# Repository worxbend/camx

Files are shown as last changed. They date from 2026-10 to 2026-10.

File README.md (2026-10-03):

<div align="center">

# 📷 CAMX

### Your webcam just unlocked movement. ✨

**ESP32 brains. Two tiny servos. One printable pan & tilt rig.**







[**🎛️ Try the control desk**](https://worxbend.github.io/camx/control/?demo=1) · [**🌀 Open the 3D studio**](https://worxbend.github.io/camx/) · [**📦 Get the downloads**](https://github.com/worxbend/camx/releases/latest) · [**🛠️ Build guide**](docs/assembly.md)

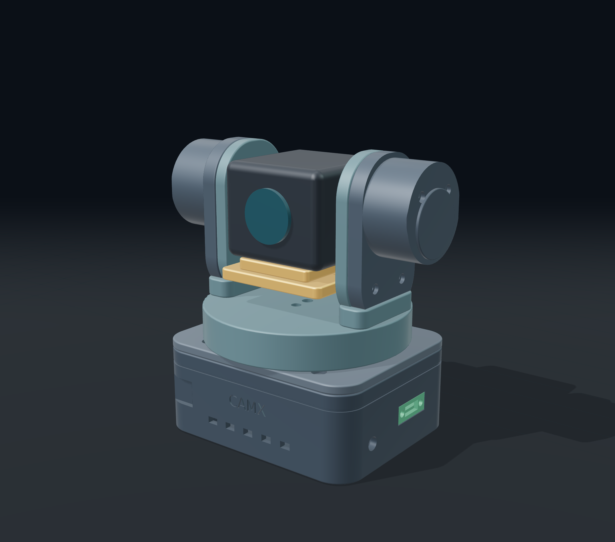
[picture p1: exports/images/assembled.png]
CAMX — actual CAD geometry rendered in the 3D studio


</div>

---

## ✨ The vision

Take an Anker PowerConf webcam. Give it a smooth pan axis, a balanced tilt cradle, and a rounded enclosure that actually looks like a device you'd keep on your desk.

The compact version uses a **100 × 82 × 38 mm base**, a **Ø92 mm pan platform** and shallow lower side shells. The complete neutral assembly is **126.6 × 91.5 × 127 mm**, including the two pivot housings. Camera fit targets the owner-stated **50 mm-wide camera**, represented by a **50 × 51 × 41 mm envelope**; verify your exact PowerConf model and folded clip.

CAMX follows the owner's hand-drawn concept: **a curved camera cradle and an ESP32 beside the pan servo in the base**, rebuilt to match your revised sketch with **matching rounded arm housings, mirrored pivot caps, a circular pan platform and a U-shaped support**. The passive housing has the same outer shape as the servo side, with bearing hardware inside. Integral standoffs let both outer covers attach with short M2 × 8 mm screws. The camera bolts on through its existing **1/4″-20 tripod thread**. The tilt-servo lead has a rear shell exit, arm tie eyes, a pan-platform notch and a separate rear base entry. An orange neutral-pose guide shows its route in the viewer; leave an external service loop for pan. The USB-C panel board and **1000 µF capacitor** get dedicated space inside. The visible USB-C metal flange fits a recessed pocket in the right wall, 0.2 mm below its outer surface, with reinforced backing and internal nuts.

> 🧪 **Prototype, with receipts.** The firmware compiles and **615 CAD/mesh/clearance checks pass**. Hardware dimensions are still provisional; physical fit and load testing are the next step. Print the fit coupon first.

**Readiness:** ready for controlled prototype commissioning after fit/power checks. Physical validation remains pending, and the Python CAD/image toolchain has an unresolved Pillow dependency constraint and 13 security alerts. Firmware/browser production audits have no known findings. [Final audit and limitations →](docs/design/remote-qa.md)

## 🌀 Spin it before you print it

[**Launch the live viewer →**](https://worxbend.github.io/camx/)

Drag to orbit. Scroll to zoom. Preview **±60° pan** and **±25° tilt**, pull the assembly apart with the explode slider, toggle hardware or wireframe, and hide individual parts. It works on desktop and phone.

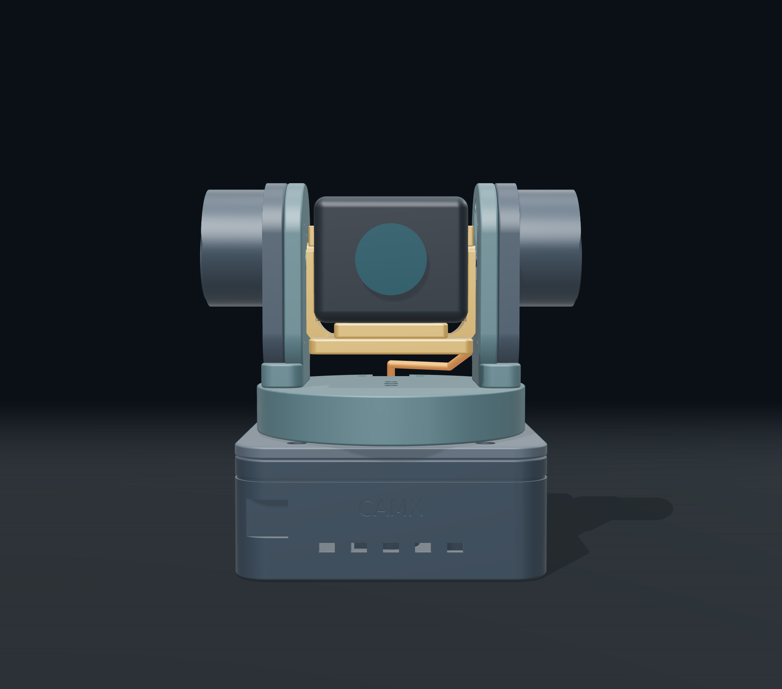
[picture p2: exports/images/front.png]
Symmetrical U-yoke — actual CAD front view


The viewer loads the **actual CAD GLB**. The webcam, PCB, servos and capacitor are simplified hardware envelopes. This site previews the design; it does not send commands to your motors.

## 📦 Pick your download

| You want… | Grab this |
| --- | --- |
| The whole project, source included | [`camx-project.zip`](https://github.com/worxbend/camx/releases/latest/download/camx-project.zip) |
| Straight to the slicer | [`camx-print-parts.zip`](https://github.com/worxbend/camx/releases/latest/download/camx-print-parts.zip) |
| ESP32 source + binaries + LittleFS client | [`camx-firmware.zip`](https://github.com/worxbend/camx/releases/latest/download/camx-firmware.zip) |
| A website you can host yourself | [`camx-viewer.zip`](https://github.com/worxbend/camx/releases/latest/download/camx-viewer.zip) |
| SolidJS control app + local bridge | [`camx-control.zip`](https://github.com/worxbend/camx/releases/latest/download/camx-control.zip) |
| File integrity checks | [`checksums.sha256`](https://github.com/worxbend/camx/releases/latest/download/checksums.sha256) |

Tagged releases publish these files automatically. Between releases, download the **camx-release-files** artifact from a successful [Build & release run](https://github.com/worxbend/camx/actions/workflows/release.yml). Artifacts are retained for 30 days; releases are the durable download location. The committed [full project bundle](exports/camx-files.zip) is also available.

**Formats on deck:** STL · 3MF · STEP · BREP · OBJ · PLY · OFF · GLB · glTF · SVG · DXF · PNG · JPEG · WebP · TIFF.

## 🧩 What's inside

| Part of the project | What it does |
| --- | --- |
| [🎛️ Firmware](firmware/) | 50 Hz servo PWM, synchronized jerk-limited S-curves, Wi-Fi controls, serial commands, saved calibration and latched STOP |
| [📐 Parametric CAD](cad/) | Thirteen printable parts, stock servo horn interfaces, adjustable component dimensions |
| [🌀 3D studio](viewer/) | Orbit, pan/tilt previews, explode, wireframe, part visibility and downloads |
| [🛠️ Assembly guide](docs/assembly.md) | Wiring, fasteners, print orientation, balance and first startup |
| [✅ Validation](exports/validation.json) | CAD solids, watertight STL/3MF meshes and sampled clearance checks |
| [🎛️ Control client](client/) | SolidJS 2 hold-to-move remote, presets, calibration, guides and local bridge |
| [🚀 GitHub Actions](.github/workflows/) | Firmware/CAD rebuilds, viewer tests, release downloads and Pages deployment |

### 🖨️ Thirteen printed pieces. Zero printed spline teeth.

`drive_arm` · `base` · `lid` · `pan_arm` · `camera_cradle` · `tilt_cover` · `bearing_retainer` · `spindle_keeper` · `tripod_nut_retainer` · `idler_cover` · `fit_coupon` · `idler_arm` · `idler_bearing_retainer`

Use your servos' original horns and center screws. A **6805 bearing (25 × 37 × 7 mm)** supports the pan platform. Steel hardware provides the camera screw and captive tripod nut.

## 🔌 The hardware lineup

- 📷 Anker PowerConf webcam — confirm the exact model, dimensions, mass and thread depth.
- 🎛️ ESP32-WROOM-32 DevKit — the photographed board has a USB-C programming port.
- ⚙️ **2 × positional SG90-type micro servos** — continuous-rotation models won't follow angles.
- 🔋 Regulated **5 V / 3 A PSU** and **1000 µF electrolytic**, rated at least 10 V.
- 🔗 Your panel USB-C module — verify its pinout, CC resistors and current rating.
- 🛞 One 6805 pan bearing and one 625 tilt bearing, fasteners, zip ties and a 1/4″-20 camera screw/nut.

**GPIO18 → pan · GPIO19 → tilt · GPIO33 → optional STOP button.** Common ground for everything. Camera USB stays connected directly to the PC. Servo power comes from the PSU, not the ESP32's 3V3 rail.

[**Read the wiring and source-isolation notes before powering up →**](docs/assembly.md#wiring)

## ⚡ First boot

1. Measure your components and update [`cad/parameters.json`](cad/parameters.json).
2. Print the **fit coupon**, then dry-fit the empty mechanism.
3. Keep servos disconnected during flashing. Follow the guide when using USB and external power.
4. Copy [`credentials.example.h`](firmware/include/credentials.example.h) to `firmware/include/credentials.h` (gitignored), set your Wi-Fi credentials and API token, rebuild and flash. Open the IP printed by the serial monitor after connection.
5. Center the servos with their horns removed, assemble, balance the camera, and expand travel carefully.

**PWM starts disabled.** STOP holds the current commanded position; DISARM releases torque. Support the camera before disabling PWM. Servo angles are commanded estimates, not encoder measurements. Automatic face tracking would require a separate host application; it is not included in this firmware.

## 🎮 A real remote. In your browser.

The **SolidJS 2** client gives CAMX a real operator interface: a sculpted press-and-hold directional pad, diagonal multi-touch, optional held keyboard arrows, three speed levels, editable presets, JSON backups, live status and a bounded activity log. A dedicated calibration workspace includes pulse settings, inversion, speed, measured travel limits, and a four-step walkthrough. Wiring, assembly and Wi-Fi guides are built in.

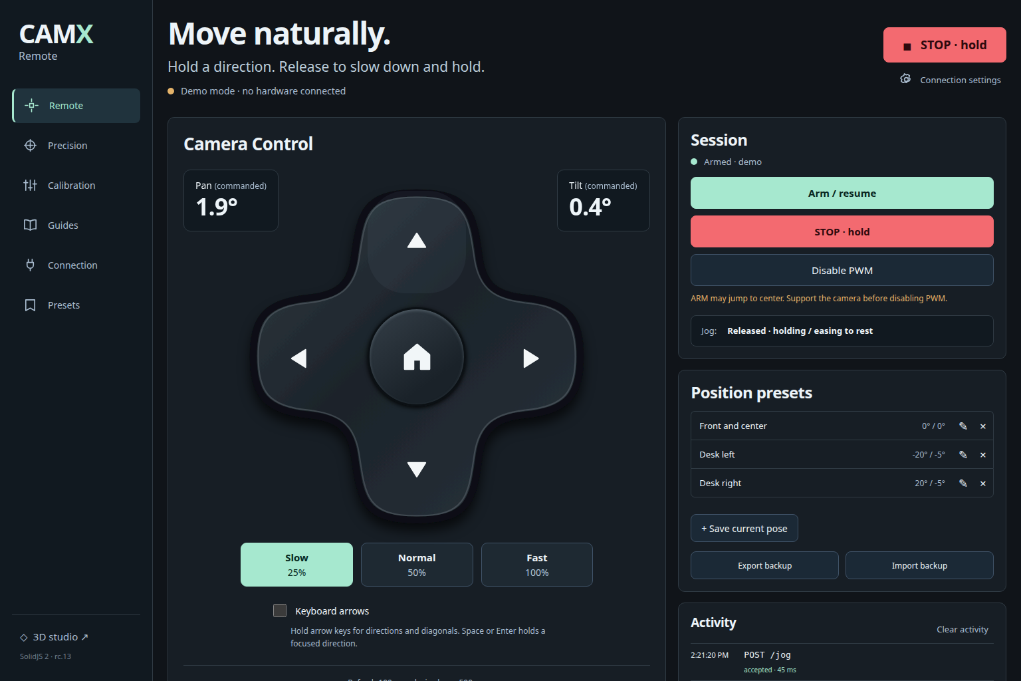
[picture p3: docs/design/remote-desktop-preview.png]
CAMX remote — actual browser interface in demo mode


**Hold to move. Release to brake smoothly.** A normalized velocity pair is refreshed every 100 ms. Firmware stops and latches if the jog lease is not renewed within 500 ms. Pointer cancellation, hidden tabs and connection loss clear held inputs; returning never resumes them. The Precision tab retains combined angle targets, sliders and fine nudges. [Why this protocol? →](docs/jog-design.md)

**STOP stays visible.** Connecting never arms the servos. Calibration saves only with PWM disabled. The optional control lease starts off; losing the connection cancels queued motion and reconnection requires deliberate ARM. Tokens remain in memory and stay out of backups and browser storage.

[**Explore the safe demo →**](https://worxbend.github.io/camx/control/?demo=1) · [**Install on your ESP32 →**](docs/control-client.md) · [**Download the client →**](https://github.com/worxbend/camx/releases/latest/download/camx-control.zip)

The Pages version is a simulation. For real control, serve the client directly from the ESP32's **LittleFS** partition at `http://DEVICE_IP/control/`, or run the included **localhost LAN bridge**. No cloud account or Internet connection is needed after installation. Webcam video and face tracking are separate host-side concerns.

SolidJS 2 is pinned to **2.0.0-rc.13**, with matching web runtime/compiler packages. It is a release candidate; dependencies and the lockfile are committed. Node 24 is recommended. [Official Solid releases](https://github.com/solidjs/solid/releases).

```sh
npm --prefix client ci
npm --prefix client run build
npm --prefix client run stage:firmware
.venv/bin/pio run -d firmware -t buildfs
# Upload configured firmware + filesystem after reviewing wiring/power isolation.
.venv/bin/pio run -d firmware -t upload
.venv/bin/pio run -d firmware -t uploadfs
```

For a desktop control station:

```sh
CAMX_DEVICE_URL=http://DEVICE_IP npm --prefix client run serve
# Open http://127.0.0.1:4175/control/
```

## 🛝 Smooth moves, built into firmware

Each accepted pan/tilt target uses a synchronized **jerk-limited S-curve**: gentle start, gradual acceleration, bounded top speed, then gradual deceleration to zero velocity and acceleration. The existing calibration **Speed** is the maximum speed, not a constant-rate jump. At the default settings, a 30° pan move from rest takes about **2.4 seconds**. Short moves reach a lower peak speed automatically.

New targets preserve the current commanded position, velocity and acceleration. Repeating the same target does not restart the ramp. The complete calculated path must stay within saved limits, including braking before a reversal. **STOP, Wi-Fi loss, watchdog expiry and DISARM remain immediate**; emergency stops do not wait for easing. Normal remote release brakes smoothly; emergency STOP holds immediately. For an absolute move longer than five seconds, explicitly enable the client's Maintain control lease or send accepted heartbeat/commands.

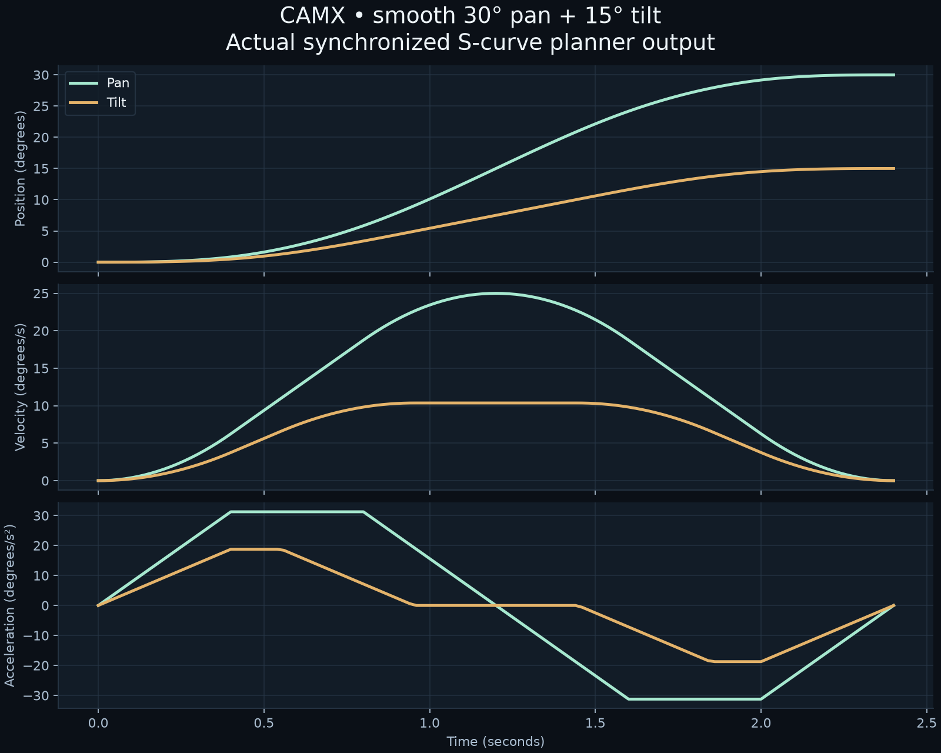
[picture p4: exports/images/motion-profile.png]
Actual firmware planner — 30° pan and 15° tilt move


The offline planner uses the vendored MIT-licensed [Ruckig 0.15.3 core](firmware/lib/ruckig/UPSTREAM.md). SG90 backlash, deadband, pulse resolution and camera balance still affect physical smoothness; there is no encoder feedback. Physical motion has not yet been verified.

## 📡 LAN control

The ESP32 joins your **2.4 GHz Wi-Fi** and serves HTTP on port 80. Send both center-relative offsets in one request; repeats do not accumulate movement. [API and hardening details →](docs/firmware-api.md)

```sh
curl -X POST http://DEVICE_IP/arm -H 'X-CAMX-Request: 1' -H "Authorization: Bearer $CAMX_TOKEN"
curl http://DEVICE_IP/move -H 'X-CAMX-Request: 1' -H "Authorization: Bearer $CAMX_TOKEN" \
  -H 'Content-Type: application/json' -d '{"pan":15,"tilt":-5}'
```

Public downloads contain **unconfigured firmware**. Build locally with your ignored `credentials.h`; configured binaries also contain secrets and must stay private.

## 🧑‍💻 Build it yourself

```sh
# Python 3.12+ and a C++ compiler
python3 -m venv .venv
.venv/bin/pip install -r requirements.txt

# Control client + matching ESP32 filesystem
npm --prefix client ci
npm --prefix client run build
npm --prefix client run stage:firmware

# Firmware + CAD + print validation
.venv/bin/pio run -d firmware
.venv/bin/pio run -d firmware -t buildfs
.venv/bin/python cad/model.py
.venv/bin/python tests/validate_cad.py
.venv/bin/python tools/test_motion.py

# Diagrams + download bundle
.venv/bin/python tools/diagrams.py
.venv/bin/python tools/package.py

# Browser studio — Node 22.12+ or a supported newer version
cd viewer
npm ci
npm run build
npm run dev
```

The CAD source uses millimetres. STL/3MF files are oriented for printing and sit at Z=0. STEP/BREP preserve assembly coordinates. GLB/glTF use metres with Y up. Vector projections are visualization references; the [dimension sheet](exports/drawings/dimensions.svg) lists defaults to verify.

For browser QA and polished stills, install Chromium with `npx playwright install chromium`, serve the built viewer, then run `node scripts/qa.mjs` and `node scripts/render-cad.mjs` from `viewer/`. Set `CAMX_QA_URL` to your preview URL. Run `.venv/bin/python tools/image_formats.py` from the root to encode captured previews. Matplotlib is the default headless preview fallback.

## 🚀 Ship it with Actions

**Every push / PR:** build the SolidJS client and LittleFS image → compile ESP32 firmware → test motion, parser and LAN bridge → regenerate and check CAD → test desktop/mobile controls and viewer → upload downloadable artifacts.

**Every `v*` tag:** run the same checks, then create a GitHub Release with all five ZIPs and SHA-256 checksums.

```sh
git tag v0.5.1
git push origin v0.5.1
```

**GitHub Pages:** the separate [Pages workflow](.github/workflows/pages.yml) builds and publishes the live studio and control demo on main/master pushes. Configure **Settings → Pages → Source → GitHub Actions**. All site assets ship locally; repository subpaths such as `/camx/` work without changing the Vite base.

<details>
<summary><strong>🧪 What was checked — and what still needs real hardware</strong></summary>

- Firmware compilation, pure C++ motion tests and HTTP/JSON parser fuzzing with sanitizers.
- Control-client unit/browser tests and three local bridge checks, including paired movement, calibration, cancellation, reconnect and token privacy.
- Thirteen valid CAD solids; watertight, oriented STL/3MF exports with matching bounds.
- Sampled pan/tilt clearance; the exact count is recorded in the validation report.
- Browser loading, pivots, explosion, visibility, wireframe, view presets, reset, downloads and guide navigation.
- Desktop **1536 × 1024** and mobile **390 × 844**, including a `/camx/` deployment path.
- Archive integrity and generated-file checksums.

Still to verify: your component measurements, printer tolerances, actual servo travel, cable slack, load balance, heat, jitter and durability. The opposite 625 bearing reduces cantilever loading. Matching 6 mm side plates, rounded foot joints and a compact base support the symmetrical assembly. The SG90 still carries part of the load; physical durability remains unverified. See the [structural review](docs/structural-review.md). Published SG90 stall torque is not a continuous load rating.

[Workflow decisions](docs/workflow.md) · [Visual concept and review](docs/design/fidelity-review.md) · [Viewer QA](docs/design/viewer-qa.json) · [Remote QA](docs/design/remote-qa.md)

</details>

---

<div align="center">

**Sketch → CAD → print → move.** 🖤

Built with **build123d · PlatformIO · SolidJS 2 · Three.js** by **worxbend**.

</div>

🔩 **Printed bearing-side joint:** print the [shoulder axle](exports/fasteners/printed_idler_shoulder_axle.stl), [matching captive nut](exports/fasteners/printed_idler_captive_nut.stl), outer washer and inner spacer from the [kit ZIP](exports/fasteners/printed-idler-kit.zip). No metal screw or nut is needed in this joint. Keep the 625 bearing. PETG/nylon and a supported fit/load trial are recommended; printed strength and durability remain unverified. The cradle remains 57.2 mm wide with a 51 mm camera opening.

📶 **Automatic recovery:** transient control-request failures no longer require manually reconnecting. The client retries status indefinitely and restores controls when the ESP32 responds, while cancelling interrupted holds and retaining explicit ARM after a device STOP.

📶 **Firmware 0.5.2 connection holds:** transport timeouts cancel motion and retain holding torque without requiring re-ARM. Reconnect, then press a direction again. Explicit STOP, physical STOP and PWM disable still require deliberate ARM. Update both firmware and the client filesystem.

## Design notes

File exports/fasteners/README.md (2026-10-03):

# Printed joint and legacy screw reference

For the requested printed assembly use printed_idler_shoulder_axle and printed_idler_captive_nut, plus the supplied washer/spacer. See PRINTED_JOINT.md. The FIT_ONLY file below is a separate legacy reference.

M5 × 12 mm under-head length; right-hand 0.8 mm pitch; 8.5 mm diameter × 3.5 mm slotted head. Simplified thread geometry, not an ISO tolerance-qualified manufacturing drawing.

**Printed model: fit checks only. Use a metal M5 axle screw and nut for the loaded camera assembly.** Do not force the printed thread into a metal nut. Print upright, head on the bed; inspect the recessed head slot in your slicer. No material or printer profile is included.

The 12 mm length matches the current assembly reference, but confirm your actual washer/bearing/spacer stack and ensure the tip and captive nut clear the camera before tightening. Use a 2.5 mm outer washer stack and a 2.7 mm M5 jam nut.

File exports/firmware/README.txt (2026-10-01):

Prefer PlatformIO upload. For classic ESP32 / 4MB only:
python -m esptool --chip esp32 --port YOUR_PORT write_flash 0x1000 bootloader.bin 0x8000 partitions.bin 0xe000 boot_app0.bin 0x10000 firmware.bin 0x290000 littlefs.bin
Filesystem address is validated in flash-layout.json for this build; do not reuse with a different partition table.
Public binaries are Wi-Fi unconfigured. Copy firmware/include/credentials.example.h to credentials.h, set your credentials and token, then build locally. Never publish configured binaries. Never flash only firmware.bin at address zero. See docs/assembly.md for wiring and first startup.

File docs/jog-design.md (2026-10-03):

# Hold-to-move remote: design and protocol

CAMX's primary remote sends direction and speed while a button is held. Release tells the firmware to brake smoothly and hold the resulting position. It does not keep adding angle offsets or queue a long series of target poses. Precise absolute angles remain available separately for measured positions and presets.

## Why a hold remote

A directional remote fits exploratory aiming: press right until the frame looks right, release, then adjust tilt. An explicit enable step and continuously renewed velocity intent are established teleoperation patterns. ROS `teleop_twist_joy` converts joystick input to scaled velocity commands and supports a required enable button; it delegates repeat behavior to its joystick source. CAMX applies the same general idea to browser buttons, without depending on ROS. [ROS teleop documentation](https://github.com/ros2/teleop_twist_joy)

A short command lease bounds how long missing input can continue movement. ROS's differential-drive controller offers stale-command stopping with a default 0.5-second timeout and velocity, acceleration, and jerk limits. Those are useful design precedents, not certification or evidence that a webcam mechanism is safe. CAMX's independent 500 ms jog watchdog is a project choice to be validated on its actual network and loaded mechanism. [ROS controller documentation](https://control.ros.org/rolling/doc/ros2_controllers/diff_drive_controller/doc/userdoc.html)

## PTZ precedents and mode choice

ONVIF's PTZ service separates absolute, relative, and continuous moves. ContinuousMove supplies signed axis velocities, an optional timeout, and zero-axis stopping; Stop is a separate operation. Axis VAPIX likewise offers paired continuous pan/tilt rates and a zero/zero stop. CAMX borrows this interaction model, but its JSON endpoints, epochs, and response schema are custom: **CAMX is not an ONVIF-compatible camera**. [ONVIF PTZ service §§5.3.3–5.3.5](https://www.onvif.org/specs/srv/ptz/ONVIF-PTZ-Service-Spec.pdf), [Axis PTZ API](https://developer.axis.com/vapix/network-video/pantiltzoom-api/)

| Mode | Intent | Best use | Delay concern |
|---|---|---|---|
| Absolute target | Go to a calibrated angle | Precision and saved poses | Repeating the same target is idempotent |
| Relative increments | Move another small distance | Discrete nudges | A delayed backlog can keep adding distance |
| Renewed velocity | Continue while current intent is held | Directional remote | Short lease and ordered release bound stale intent |

## Release and fault behavior

| Trigger | Result | Resume |
|---|---|---|
| Pointer/key release | New zero/zero jog, jerk-limited braking, holding torque retained | Another deliberate hold while armed |
| Cancellation, blur, hidden page, navigation | Held input cleared; best-effort release sent | New deliberate hold; no replay |
| 500 ms jog lease expiry | Immediate STOP and epoch invalidation | Explicit ARM |
| Device Wi-Fi loss or physical STOP | Immediate STOP and epoch invalidation | Inspect mechanism, recover link/release switch, explicit ARM |
| Browser/network request failure | Client stops sending intent; release may not reach device, so device lease remains the fallback | Explicit reconnect/ARM as required by returned state |
| DISARM | PWM disabled; camera may drop | Support camera, explicit ARM |

The 25% default lowers the requested maximum velocity while retaining configured acceleration and jerk constraints. Its braking path is generally shorter than full-speed motion under the same constraints; actual servo response and stopping distance still require loaded measurement.

## Request contract

After explicit ARM, read `control_epoch` from the returned device status. Send `POST /jog` with exactly four fields:

```json
{"pan":0.25,"tilt":0,"epoch":123456,"seq":1}
```

`pan` and `tilt` are finite normalized rates from −1 to +1, scaled by each axis's calibrated speed. They are not degrees or cumulative increments. Default remote strength is 25%. Diagonals put both directions into the same request. The actual positive direction follows calibration.

`epoch` and `seq` are unsigned 32-bit integers. An ARM establishes a fresh epoch. Sequence numbers must increase within it. Wrong epochs and already accepted or older sequence numbers are rejected, so delayed requests within a running controller cannot restore a previous hold after a newer release or STOP. Firmware seeds a nonzero boot epoch using ESP32 randomness to reduce cross-reboot collisions. Epochs are ordering guards, not authentication or guaranteed persistent identities; reconnect and explicitly ARM after a restart.

While held, send the current intent about every 100 ms. Do not build a backlog: retain only the newest unsent intent. On release, send a newer sequence with both rates zero:

```json
{"pan":0,"tilt":0,"epoch":123456,"seq":8}
```

This is a deliberate soft release, not emergency STOP. Emergency STOP cancels the current trajectory immediately and requires ARM before resuming. Release can travel a little farther while decelerating; leave physical and cable clearance.

Every mutation requires `X-CAMX-Request: 1`. When configured, use `Authorization: Bearer TOKEN`; send JSON as `Content-Type: application/json`. Local HTTP remains plaintext, same-origin, and intended for a trusted LAN.

Status includes `control_epoch`, `jog_seq`, `jog_pan`, `jog_tilt`, `jog_active`, and `jog_lease_ms`, alongside existing armed, stopped, target, and calibration fields. These are commanded states, not encoder measurements.

## Leases and invalidation

The firmware accepts renewed jog intent only for the current epoch. A nonzero accepted rate renews the lease; an accepted zero/zero release disables the short lease and begins jerk-limited braking. If an active jog reaches 500 ms without renewal, it immediately holds position and invalidates that epoch. Status requests and `/heartbeat` do not renew a jog lease. Invalid JSON/rates return HTTP 400; state, epoch, sequence, or planner rejection returns HTTP 409; accepted requests return HTTP 200 with status. ARM is explicit; reconnecting cannot revive an old hold.

STOP, DISARM, Wi-Fi loss, motion watchdog expiry, and accepted absolute `/move` or `/home` commands invalidate prior jog intent. Switching from the remote to an absolute pose is deliberate, and stale jog requests cannot override that pose. If sequence space is exhausted, stop and ARM for a new epoch instead of wrapping into previously used sequence values.

## Browser input lifecycle

The client captures active pointers so release can be observed when a finger or mouse leaves its button. Pointer capture does not remove the need to handle cancellation: browsers may cancel a pointer when they take over a gesture or interrupt input. CAMX clears holds on release, cancellation, capture loss, window blur, page hiding, navigation, disconnect, and emergency STOP. [Pointer capture](https://developer.mozilla.org/en-US/docs/Web/API/Element/setPointerCapture), [pointer cancellation](https://developer.mozilla.org/en-US/docs/Web/API/Element/pointercancel_event)

Background timers can be throttled. The page-visibility signal therefore clears active input rather than assuming a background tab can reliably maintain motion. The device watchdog remains responsible if a cleanup packet cannot arrive. [Page Visibility API](https://developer.mozilla.org/en-US/docs/Web/API/Page_Visibility_API)

Keyboard arrows represent held directions, including diagonals. Key repeats do not accumulate moves. Key-up releases the corresponding direction. Typing in an input, textarea, select, or editable field does not aim the camera; keyboard motion is limited to the remote surface and explicitly enabled. No held direction is restored after reconnect or returning to the tab.

## HTTP tradeoffs

Small periodic HTTP requests reuse the firmware's existing bounded parser, token handling, and local bridge. They provide an inspectable one-package two-axis API and are straightforward to exercise with mocked browsers and native parser tests. Epochs and sequence numbers protect ordering independently of browser cancellation: aborting a fetch cannot retract a request the ESP32 already received.

WebSocket could reduce framing overhead and improve bidirectional updates. It would add another connection lifecycle, framing implementation, buffering policy, and release path to this small ESP32 controller. At the initial 10 Hz intent rate, bounded HTTP is a reasonable starting point; hardware testing must assess latency, packet loss, simultaneous clients, and servo responsiveness before claiming it is adequate under all conditions.

Repeated absolute offsets remain appropriate for saved poses and precise framing. They are less suited to press-and-hold interaction because the browser must otherwise estimate device position or generate successive targets during stalls and delays. Jog moves that timing and safe-limit responsibility into firmware.

## Verification limits

Browser tests use simulated devices and verify sustained intent, paired rates, increasing sequences, release priority, cancellation, focus guards, legacy capability detection, privacy, and responsive controls. Native firmware tests check parsing, leases, stale commands, and motion math. Neither establishes real motor torque, bearing clearance, actual stopping distance, Wi-Fi timing, or electrical safety. Bench-test an unloaded mechanism and a secured representative dummy before mounting the camera.

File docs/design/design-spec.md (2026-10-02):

# CAMX viewer visual specification

Built-in imagegen was used for the UI concept at `viewer-concept.png`; no API/CLI fallback was used. Product visuals in the finished interface come from the actual build123d GLB, not from a generated product picture.

## Concept prompt

Use case: ui-mockup. One complete 1536 × 1024 desktop screen for CAMX, an interactive 3D CAD viewer for an ESP32-powered DIY pan/tilt camera. Refined engineering studio. Dark navy #0b1017, pale type, mint #a6e8cf accents, #26313b borders. Header CAMX, 3D studio, Build guide, Download files. Open 70–74% canvas and 26–30% inspector, no card grid. Heading “Made to move.” and “Your camera. A new point of view.” Realistically proportioned 100 × 82 × 38 mm base, slim right arm, curved amber camera cradle, square black webcam. Subdued floor grid. Canvas hints “Drag to orbit · Scroll to zoom”. Perspective/Front/Side/Top buttons. Inspector Assembly, Explore the mechanism, Pan ±60°, Tilt ±25°, Explode 0–100, Show hardware, Wireframe, Reset view. Print parts, STEP assembly, Build instructions links. Footer Parametric design / build123d and Prototype · verify fit before printing. Crisp native text, restrained modern sans serif, no fake metrics or decorative badges. Mobile stacks canvas above inspector. Actual implementation must render CAD rather than use the concept as a screenshot UI.

## Tokens and components

- Canvas/background #0b1017; border #26343f; text #f2f4f8; secondary #b9c7d4; mint #a6e8cf.
- System sans serif, main heading 56 px desktop / 42 px mobile, inspector heading 40 px / 34 px, controls 13–18 px.
- Open canvas, one right inspector with dividing rule, 88 px header, 62 px footer.
- Outlined mint download/reset buttons; mint slider progress/thumbs; filled switch controls; line icons with 1.7 px strokes.
- Perspective view by default; orbit/zoom; pan and tilt pivot groups in model coordinates; per-part explosion offsets and visibility.
- No external font/CDN dependencies. All assets included in static build. Model loading error keeps downloads available.

## Intentional functional/geometry differences from the concept

- The owner approved a second tilt support with an opposite 625 bearing. The actual model now has two cradle cheeks, matching rounded full-height housings, pivot caps, a pan cowl and rounded enclosure edges.
- Show actual CAD edges, pan turntable, screw apertures, vents, retained tripod nut and approximate camera/hardware envelopes rather than idealized product surfacing or invented optics.
- Add live angle and explosion readouts and a collapsed Part visibility control to make the viewer useful.
- Show hardware toggles all nonprintable hardware, including the camera. Part visibility enables finer control.
- Desktop can scroll with the part list expanded; its collapsed studio fits the normal desktop viewport. Mobile stacks controls after the canvas.

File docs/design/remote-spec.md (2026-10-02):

# CAMX remote visual specification

The owner's remote images specify a large four-direction sculpted pad, circular center action and a phone-first layout. The matte charcoal reference is primary; mint and coral preserve CAMX's existing palette. The generated concepts `remote-concept.png` and `remote-mobile-concept.png` guide composition. The functional control is native SVG and CSS, not a generated bitmap.

## Concept prompts and composition

Desktop prompt: a 1536 × 1024 CAMX operator console, charcoal canvas, left task rail, heading “Move naturally.”, commanded pan/tilt readouts, large concave four-lobe directional cross, filled white arrows, circular Home, slow/normal/fast controls, right session/presets/activity column and globally accessible coral STOP. No webcam video placeholder or invented television features.

Mobile prompt: adapt that same concept to a 390 × 844 logical viewport with compact branding and heading, paired readouts, approximately 300 px pad, speed row, optional keyboard control, ARM/Disable PWM, persistent STOP and compact bottom navigation. Longer session details may scroll below the fold.

## Tokens

- Canvas `#101419`; panel `#171e25`; subtle border `#303b44`.
- Matte pad with native gradient, thin highlight rim and soft ambient shadow.
- White filled direction triangles and native Home glyph; consistent small navigation SVG icons.
- Mint for deliberate ARM and selected speed; coral for STOP; amber dot/text for demo.
- System sans-serif typography. Desktop title about 48 px, mobile 28 px; commanded values about 40/32 px.
- Desktop left rail about 230 px; main remote and compact right context column. Mobile prioritizes reachability and scrolling outside the pad.

## Functional hierarchy

Remote is primary. Pointer capture tracks independent held directions; opposite inputs cancel and perpendicular inputs form a diagonal. A speed change updates normalized rate, not an integrated browser angle. The center Home is a deliberate absolute action. Precision preserves sliders, fine nudges and combined degree targets. Calibration, guides, connection and editable presets remain available.

STOP is always reachable, including fixed placement on phone across workspaces. ARM never occurs on connection, tab return or reconnect. Only the pad suppresses touch scrolling. Visible state distinguishes held, braking, idle, stopped and disabled PWM. Readouts label **commanded** position, since SG90 has no encoder feedback.

## Intentional concept copy/layout deviations

- Generated example angle values are not initial state: actual status supplies them.
- Demo uses a dot and text instead of a generated badge.
- Existing preset angles are preserved instead of generated example angles.
- Invented “Move / Create / Capture” footer copy is omitted.
- Native icons and functional labels replace generated icon artifacts.
- Compact mobile ARM placement may precede the pad to keep enable and STOP reachable without scrolling. The concept is not a rigid pixel target where accessibility conflicts.
- Lease timings describe this prototype's protocol, not a certified motion guarantee.

Browser fidelity is assessed at native 1536 × 1024 and 390 × 844 alongside functional pointer, keyboard and lifecycle checks. Actual browser previews are published separately from concepts.

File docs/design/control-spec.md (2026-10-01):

# CAMX Control visual and interaction specification

Source: `control-concept.png`, generated with the built-in image generation tool for a complete 1536×1024 task-oriented desktop control app. The owner requested autonomous implementation without questions; the concept is selected as the implementation reference.

## Visual system

Dark instrument console, matching the existing CAMX studio: navy canvas `#0b1017`, slightly raised surfaces `#121c27`, cool fine borders `#283747`, mint `#a6e8cf` for primary actions and axes, amber `#e4b36a` for fine-step selection, coral `#f36a70` for STOP. Geometric system sans, restrained 12px corner radii, no glowing decoration, gradients or video claims. Typography: 38px main heading desktop, 26px panel headings, 16px form labels, 14px secondary text; scale down responsibly on narrow viewports. Bright text `#edf4f8`, muted `#aabdd0`.

Left rail ~220px with CAMX typographic wordmark, Control desk, Control/Calibrate/Guides/Connection navigation and bottom 3D studio link. Main gutters 24px; header Make your move. and actual connection/demo status, connection settings at right. Control region has an expansive XY pad plus two-axis slider/numeric/nudge controls, fine-step selector and optional keyboard control. Right session/presets rail ~300px; STOP clearly visible and easy to operate. Activity occupies a simple full-width chronological table/list below. Preserve border hierarchy, readable form sizing and generous pad area.

## Functional surfaces

- Control: physical-state-aware ARM/Home/STOP/Disable PWM, combined numeric pan/tilt requests, drag pad, fine steps, guarded keyboard, editable presets, import/export, optional explicit maintain-control heartbeat, bounded scrubbed activity log.
- Calibration: dedicated two-column settings/wizard surface in the same visual language; axis selection, center/low/high pulse µs, degree limits, speed and invert, validation, read device status, apply only disarmed, import/export configuration without secrets. Step instructions explain horns-off center, installation, direction, measuring limits and loaded validation. Applying calibration never arms or moves automatically.
- Guides: readable task articles/checklists for wiring, USB source isolation, Wi-Fi configuration, LittleFS client install, center/direction/limits, bearings/balance and host API examples. Code blocks are scrollable; no fabricated video stream or automatic face tracking.
- Connection: device/server details, memory-only bearer token, connect/disconnect, explicit offline demo, IP/hostname guidance and mixed-content explanations. Never auto-ARM on reconnect.

## Responsive and accessibility

At widths below ~1100px use a thinner rail and scale control columns; below ~850px stack the session/presets below the pad and move navigation to a compact header. At 390px every control is readable and reachable without horizontal page overflow. Touch targets at least 40px, native labeled inputs/buttons, focus-visible rings, reduced-motion support, status live region. Device-disconnected, stopped, physical STOP and calibration states gate motion controls.

## Intentional fidelity adjustments

The generated reference depicts an armed demo at pan12/tilt−4. Actual app defaults must be disconnected/disarmed (or clearly labeled demo), with zero angles until the user deliberately acts. 'Maintain control' starts OFF for safety although the reference shows a check. Arm button behavior/text may reflect the actual session state. Add required functional tabs/forms using this exact component system rather than duplicating screenshot values as fixed content. No token or credentials stored in localStorage, exported files, activity or screenshots.

## Concept prompt summary

Built-in image generation: complete CAMX Control desktop app, dark navy/mint/amber/coral palette, left task rail, large XY aiming pad, paired pan/tilt controls, explicit session controls, editable preset list and activity. All interface elements remain native HTML/CSS/Solid components. No fake camera/video or invented metrics.

Calibration reference: `calibration-concept.png`, built-in image generation using the same palette, rail and component system. Four plain numbered steps Center/Direction/Limits/Verify; pulse-field form with Pan/Tilt selection, pulse-range diagram and save/reload/import/export; right step instructions and serial sample; bottom pre-movement checklist. Ignore the generator's accidental desktop window titlebar: this is a browser application. Commands are explanatory examples, not automatically executed scripts. Generic nav icons should remain consistent with the control reference across tabs.

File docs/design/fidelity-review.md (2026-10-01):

# Viewer review

Working concept: [viewer-concept.png](viewer-concept.png). Browser captures: [viewer-desktop.png](viewer-desktop.png), [viewer-mobile.png](viewer-mobile.png). Both concept and rendered screenshots were inspected with `view_image`. Browser/IAB was unavailable; Playwright Chromium supplied the fallback. Native concept viewport: 1536 × 1024. Mobile: 390 × 844.

| Comparison | Evidence / result |
| --- | --- |
| Copy | CAMX, Made to move., Your camera. A new point of view., Assembly and every requested main control/link preserved. Additional angle readouts and collapsed part list are intentional functional additions. |
| Layout | Open left canvas and right inspector; header navigation, bottom view selector and narrow footer. Fixed an overly tall inspector so the collapsed desktop studio fits the target viewport. |
| Typography | 56 px main heading, 40 px inspector title and deliberate control sizes; mobile heading 42 px and stacked layout. System fonts replace the mockup's raster font. |
| Palette | Dark navy and mint match the concept tokens. Reduced lighting/exposure after a first browser capture made the model and ground too pale. |
| Asset treatment | Real GLB generated from the printable CAD; no product render as fake interactive UI. Geometry deviations are listed in design-spec.md. |
| Icons and controls | Native outline icons, outlined buttons, mint sliders and switches; controls update real scene transforms/materials/visibility. |
| Responsive behavior | Phone navigation fits, canvas and controls stack, download icon remains visible, no horizontal overflow. |

Above-the-fold copy diff: core concept strings retained; live numeric values and Part visibility are intentional additions. The chrome was visually verified against the working design. Actual CAD geometry and simplified hardware envelopes are intentional deviations, so the model is not claimed as a pixel-identical copy of the concept product picture.

Functional coverage is recorded in viewer-qa.json: loading, pan/tilt, explosion, hardware, wireframe, per-part visibility, four view presets, reset, downloads, guide and mobile overflow. No page errors observed. Physical assembly validation remains outstanding.

## Two-sided revision

The owner's requested update adds an opposite 625 bearing support, 6 mm main arm and root braces. Rounded plan corners and small edge fillets soften the base, lid, arms, hood and cradle. Functional bearing seats, stock horn recesses and screw paths preserve fit geometry. The actual CAD and revised motion groups are used for the refreshed browser captures. The original concept remains a visual direction, not a manufacturing reference.

## Symmetrical U-yoke redesign

The latest owner sketch replaces the earlier asymmetric construction. The two outer covers are checked as exact mirrored solids in CAD validation. Both side shells are now generated from the same rounded profile and mirrored exactly across X=0, including their circular pivot caps. Internal functional geometry differs for the SG90 and 625 bearing. Matching cradle cheeks, a wider rounded base and a circular rotating platform with an enclosing pan cowl carry the new PTZ-inspired silhouette. The original UI concept remains a styling reference only.

Final desktop and phone captures were inspected against the original UI concept. The new symmetrical geometry is an intentional owner-requested departure from that concept. Desktop framing and the mobile camera distance were adjusted for the wider body; snapshot capture forces a viewport resize before rendering to prevent stale frames after the part list collapses.

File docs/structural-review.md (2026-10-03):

# Structural review — two-sided revision

The opposite 625 bearing, matching 6 mm arm plates, rounded foot supports, and M2 through-bolted tilt-servo ears improve the original cantilever arrangement. This is an engineering prototype, not a verified load-rated product. No physical durability test or finite-element analysis has been performed.

## What the added bearing changes

With a 150 g camera and an approximately 35 mm lateral offset, the original one-sided support carries a bending moment of `0.150 × 9.81 × 0.035 = 0.052 N·m`. A support at each side lets the assembly share vertical loads and reduces bending at the servo output. Load sharing depends on alignment and actual centre of gravity; it is not guaranteed to be exactly equal. The opposite bearing does not increase the servo's available drive torque or protect its plastic gears from a jam.

The 625 bearing dimensions are 5 × 16 × 5 mm ([SKF catalogue](https://cdn.skfmediahub.skf.com/api/public/0901d196802809de/pdf_preview_medium/0901d196802809de_pdf_preview_medium.pdf)). The current owner-requested version uses a printed shoulder axle (4.85 mm smooth journal, 12 mm under-head length), a paired printed 2.7 mm captive nut, a 2.5 mm outer washer and a 1.4 mm inner spacer. Washers/spacer must contact the inner race only. Incorrect stack length can preload or bind the bearing. The bearing shoulder has clearance around the spacer; inspect the printed fit and the camera-side axle tip before use.

For an ideal rectangular section with the same width, changing thickness from 4 to 6 mm increases bending section modulus by `(6/4)^2 = 2.25` and elastic bending stiffness by `(6/4)^3 = 3.375`. These ratios describe a simplified section, not the strength of the printed assembly. Rounded arm-foot transitions reduce abrupt load transfer; layer adhesion, screw holes, mounting ears and print defects still govern failure.

## Torque and stability

Camera gravity torque is `mass_kg × perpendicular_offset_cm` in kgf·cm: 150 g at 1 cm is 0.15 kgf·cm; at 3 cm it is 0.45 kgf·cm, before cradle weight, acceleration and cable drag. [TowerPro lists 1.8 kgf·cm at 4.8 V as stall torque](https://towerpro.com.tw/product/sg90-7/), which is not a continuous operating rating. Balance the assembled cradle near the tilt axis and use slow movements. For heavy cameras, frequent tracking, heat, jitter or backlash, redesign around stronger servos and independent bearings on both sides.

The compact base footprint is 100 × 82 mm. For an illustrative measured total mass of 0.4 kg, a CG margin of 35 mm, and a cable pull applied 127 mm above the desk, the static tipping force is only `0.4 × 9.81 × 0.035 / 0.127 = 1.08 N`. These are illustrative assumptions, not measured device properties. The reduced footprint decreases tipping resistance. Measure actual mass, feet placement and CG, secure the device using the captive 1/4-20 socket, and leave relaxed cable loops. Rubber feet reduce sliding but do not prevent tipping; this design is not a monitor clamp.

## Print and commissioning checks

Use PETG, at least four perimeters, sound layer adhesion and local supports as needed. [Prusa's orientation guidance](https://help.prusa3d.com/article/modeling-with-3d-printing-in-mind_164135) explains why loading across layer joints can weaken a part. Inspect screw bosses and arm roots for splitting. Do not treat infill percentage as a load rating.

1. Measure all hardware and print the fit coupon. Check both tilt supports are coaxial and the empty mechanism turns freely without motor power.
2. Secure the base. Fit a dummy matching the camera's measured mass, dimensions and CG; add a loose safety tether. Keep hands clear of pinch points.
3. Centre and calibrate with horns removed. Start with narrow pulse limits and expand while measuring actual angles. Firmware angles are estimates.
4. With the dummy installed, check neutral and travel endpoints for at least 15 minutes each. Watch for creep, binding, warm servos, jitter, cable tension and screw loosening. Stop immediately if any appear; never sustain a stall.
5. Cycle slowly through the intended range, inspect the printed roots and horn fasteners, and retest after cooling. A successful bench check is preliminary evidence, not a fatigue-life certification.
6. Install the real camera only after fit, stability and electrical checks pass. Support it whenever PWM or power is removed; DISARM can let it drop.

The generated validation report checks CAD solids, exported meshes and finite sampled clearances. Hardware envelopes are provisional, and cables, full horn details and all fasteners are not collision-modeled. It cannot establish that the construction will never break.

## Symmetrical revamp

The compact 100 × 82 × 38 mm enclosure replaces the broad base. Matching side shells have a shallow 7 mm lower spine and full depth only around the servo-sized pivot. The 92 mm pan cowl hides the spindle. The passive shell protects the 625 bearing, axle and internal arm; it is not itself the primary tilt bearing support. Integral standoffs retain short M2 × 8 mm cover screws. Less hollow volume does not establish strength or stability: repeat loaded movement, cable pull, torque, heat and RF checks with the actual assembly.

## Printed axle qualification

The printed axle and nut are a prototype alternative to the earlier metal joint. Geometry and paired thread clearance are checked, but this does not establish strength or a safe working load. Layer separation, thread stripping, support damage and creep can loosen or fracture the joint. Print the axle horizontally with supports and use PETG or suitable nylon, then trial-fit without forcing the threads. Retain gently rather than torque-clamping the bearing. Check unloaded rotation and camera clearance, then test with a supported dummy load before attaching the camera. Use a safety tether and inspect for cracking or increasing play. No fatigue life, temperature margin or loaded durability is claimed.

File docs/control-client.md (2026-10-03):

# CAMX Control Studio 🎛️

The SolidJS client brings pan and tilt, saved poses, calibration, and assembly guidance into one local dashboard. It controls the ESP32 mechanism; it does not carry webcam video or perform face tracking. The public GitHub Pages version is an interactive demo. Browser demo movements never reach a servo.

## Choose how to connect

**Device-hosted client:** build the static client and install its LittleFS image using PlatformIO. Open `http://DEVICE_IP/control/` in a browser. The client and API share an origin, so no CORS setup is required. Firmware keeps the compact fallback page when the rich client is not installed.

**Local bridge:** use Node.js 24 LTS (or a version satisfying `client/package.json`) and the client source. From the repository root:

```sh
cd client
npm ci
npm run build
CAMX_DEVICE_URL=http://192.168.1.50 npm run serve
```

Open `http://127.0.0.1:4175/control/`, or the local URL printed by the server. Replace the example address with the IP printed by the ESP32 at 115200 baud. The bridge serves the built dashboard and forwards its API calls to the configured device. Keep it bound to localhost. It does not discover devices or make a public cloud connection.

The HTTPS GitHub Pages demo cannot directly control a plaintext LAN ESP32: browser origin and mixed-content restrictions apply. Use the device-hosted client or local bridge for real control.

## Build and flash the device-hosted client

Install Node.js 24 LTS and Python/PlatformIO, then run the client build. Explicitly stage the built assets into `firmware/data/control`, then build and upload the LittleFS image:

```sh
cd client
npm ci
npm run build
npm run stage:firmware
cd ../firmware
pio run -t upload
pio run -t buildfs
pio run -t uploadfs
```

Configure Wi-Fi first by copying `firmware/include/credentials.example.h` to the Git-ignored `credentials.h`. Enter your 2.4 GHz SSID, password, and optional long API token. Build configured firmware locally. Do not publish configured binaries: credentials are embedded in them. A filesystem upload replaces its existing contents; calibration is retained in ESP32 NVS separately.

## First movement

1. Secure the base, support the camera, and confirm wiring and safe servo endpoints. Start with the servo horns removed on a new build.
2. Open the real local dashboard. Enter the token if configured and connect. Connecting only reads status; it does not enable PWM.
3. Inspect the current saved limits, pulse settings, STOP state, and connection status.
4. Deliberately choose **Arm / resume**. First enable assumes mechanical center and can jump; SG90 servos have no position feedback.
5. Hold a directional button on the Remote to move; release to brake smoothly. Begin at the default 25% speed. For exact angles, use Precision or a saved pose. Home commands both offsets to zero.
6. Use **STOP · hold** to cancel motion while retaining holding torque. Use **Disable PWM** only with the camera supported.

Precision movement sends both absolute offsets:

```json
{"pan":15,"tilt":-5}
```

Firmware eases absolute Precision and Home moves with a synchronized jerk-limited S-curve. These moves start gently, accelerate to at most the calibrated Speed, then slow smoothly to rest, with both axes finishing together. Changing absolute targets preserves velocity and acceleration; repeating a target does not restart easing. Jogging applies bounded acceleration and jerk independently to each axis. STOP remains immediate.

Values are degrees from calibrated center, not increments. Firmware positions and the dashboard visualization are commanded estimates, not measured angles. Limits apply to both values atomically.

Connection loss cancels client motion intent; reconnection never automatically arms or resumes it. Firmware holds position after Wi-Fi loss or five seconds without an accepted movement/ARM command, preserving the existing armed state. Status polling does not renew this timeout. Any optional live-control lease only renews an explicitly active session; stop it when finished. A browser STOP requires a working network connection: use the GPIO STOP input for local intervention that does not depend on a browser request. It is software-polled and is not a hardwired power cutoff.

The directional remote uses `POST /jog` with paired normalized rates, a control epoch returned by ARM, and a strictly increasing sequence. It renews intent approximately every 100 ms only while held. Releasing sends both rates zero with a newer sequence and starts jerk-limited braking. This may travel farther than an emergency STOP. Pointer cancellation, lost capture, window blur, page hiding, navigation, disconnect, and STOP clear held input. Keyboard arrows support diagonals when enabled and ignore editable fields.

```json
{"pan":0.25,"tilt":0,"epoch":123456,"seq":1}
```

A nonzero jog has a separate **500 ms lease**. Missing renewal immediately holds position and invalidates the epoch; `/status` and `/heartbeat` cannot extend that lease. A zero/zero release ends the short lease. Recovery requires a new hold; ARM is required only after explicit STOP or PWM disable. Old or duplicate sequences and previous epochs cannot revive motion. Older firmware without jog capability disables held directions; absolute Home and Precision remain available. See the [jog design and protocol](jog-design.md) for details and tradeoffs.

## Calibrate with measured angles

Calibration is accepted only while PWM is disabled. The dashboard exposes center, low and high pulse widths, angle endpoints, inversion, and speed for each axis. Pan is axis `0`; tilt is axis `1`.

1. Remove horns, disable PWM, and start with narrow pulses: low `1400`, center `1500`, high `1600` µs. Use small ±10° limits and 5°/s speed initially.
2. Save one axis, then the other. The dashboard rereads status to confirm the device's saved values.
3. Arm unloaded to center the shafts. Mark their positions, disconnect power, and mount horns so the camera faces forward and is level.
4. Arm and test pan alone, then tilt alone in small steps. Change inversion while disarmed if your chosen positive direction is reversed.
5. Measure travel using a protractor or angle gauge. Disable PWM before each adjustment, then expand pulse endpoints by approximately 10–20 µs per trial. Maintain clearance from collisions, cable tension, and mechanical servo stops.
6. Balance and mount the camera, then repeat slowly with a secured base and tether.

Changing angle limits alone does not expand physical travel: they are mapped to your pulse endpoints. Maximum CAD envelope is pan ±60° and tilt ±25°; measured safe travel may be smaller. Never calibrate by driving into a hard stop. Saved calibration survives reboot.

The calibration request is:

```json
{"axis":0,"center":1500,"low":1400,"high":1600,"minimum":-10,"maximum":10,"invert":false,"speed":5}
```

The endpoint is `POST /calibration`. Every mutation requires `X-CAMX-Request: 1`; a configured token uses `Authorization: Bearer TOKEN`. See the [firmware API](firmware-api.html) for the full contract and [assembly guide](build.html) for electrical isolation, fasteners, and power connections.

## Saved poses and privacy

Saved poses are browser-local convenience settings. **Save current pose** captures the latest device-reported commanded pan/tilt at the moment you save, including a position updated after jog braking. It does not save an unsent Precision draft. These are commanded estimates, not encoder measurements. Editing an existing preset preserves your explicitly edited values. Imported poses still pass current device limits and require deliberate ARM before motion. Review a preset before recalling it. Exported presets contain pose data, not Wi-Fi credentials or bearer tokens. The connection token stays in memory for the active page session; reenter it after reload. Do not expose the controller or bridge to the Internet: device HTTP traffic is plaintext.

## Development and verification

```sh
cd client
npm ci
npm run dev
npm run build
npx playwright install chromium
npm test
```

Browser tests use simulated HTTP responses and demo state. They verify combined requests, explicit arming, stop/disarm, calibration, presets, keyboard focus guards, and responsive layouts without operating motors. These checks complement firmware parser and movement tests; they do not establish real servo clearance, torque, Wi-Fi reliability, electrical safety, or emergency response under load.

## Automatic connection recovery

After Connect, the client retries status requests every second indefinitely, including after a failed jog request or failed initial connection. A request can take up to 2.2 seconds, and polls do not overlap. Recovery restores the controls from the current device status and clears the connection error without requiring another Connect click. Explicit Disconnect stops retries. Interrupted holds and queued movement commands are cancelled and never replayed. If the firmware has latched STOP or disabled PWM, ARM remains an explicit action; a fresh pointer or key press is required to jog again.

## Jog speed

The remote starts at Normal (50%). Slow is 25% and Fast is 100% of each axis's calibrated maximum speed. With default limits of 25°/s pan and 15°/s tilt, Normal requests 12.5°/s and 7.5°/s; Fast requests 25°/s and 15°/s. The remote shows both requested rates. Acceleration and braking remain jerk-limited. For higher maximum rates, disable PWM and edit the individual speed fields in Calibration, preserving measured pulse endpoints and angle limits. Saved calibration overrides firmware defaults. Rates and displayed angles are commanded values, not measurements from SG90 position feedback.

## Displayed 60° but only a few degrees of physical movement

The narrow startup pulses (1400/1500/1600 µs) are deliberately conservative, but the initial pan angle labels span −60° to +60°. A commanded +60° therefore emits only 1600 µs, not a verified physical 60° rotation. This also makes actual movement much slower than the requested degree rate until calibrated. The SG90 cannot measure the angle for us.

Start unloaded with horns/linkage removed and a shaft marker. Measure the actual negative and positive angles at your current low/high pulses relative to the center. While disarmed, enter those measured angles in Calibration instead of the nominal labels. Then widen the pulse endpoints in 10–20 µs trials, disarming before every save and measuring the new endpoint angles; update the corresponding degree fields after each measurement. Stop before binding, buzzing or excessive heat. Calibrate pan and tilt separately. Refit the centered mechanism and narrow both pulse endpoints and their matching measured angle limits to physically tested clearances. Changing only the degree labels does not reduce the physical endpoint travel. Do not blindly choose 700/2300 µs: these are software bounds, not guaranteed safe endpoints for your motor or assembled mechanism. The initial numeric labels should not be interpreted as a measured servo specification.

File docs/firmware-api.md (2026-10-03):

# CAMX firmware HTTP API

## Configure and connect

Copy `firmware/include/credentials.example.h` to `firmware/include/credentials.h`, then fill in your 2.4 GHz SSID, password and a long random `API_TOKEN`. This header is ignored by Git. Build/upload with PlatformIO as described in the assembly guide. No credentials means Wi-Fi stays unconfigured; serial remains available. No AP, OTA or cloud service is enabled. Credentials are not printed or returned by the API.

The assigned DHCP IP is printed at 115200 baud. Use a router DHCP reservation for a predictable address; the DHCP hostname is `camx` (mDNS is not implemented). HTTP starts after the station connects. Reconnection is attempted every 10 seconds indefinitely, including initial connection failure, wrong credentials and router outages. There is no attempt limit or forced reboot. A latched Wi-Fi event records brief disconnects even if reconnection happens between loop iterations. A detected disconnect cancels motion and preserves the existing armed state; a fresh command after reconnection can move again, while explicit STOP stays latched.

Public release binaries are deliberately unconfigured. Build your own to connect to Wi-Fi. Configured binaries embed the credentials and token. Packaging refuses a checkout with a private credentials header; use a clean checkout for public releases. Never upload private BIN/ELF files.

## Request contract

| Method | Path | Behavior |
|---|---|---|
| GET | `/` | Small local control page; enter token if configured |
| GET | `/control/` | SolidJS control app from uploaded LittleFS filesystem |
| GET | `/status` | Commanded positions, targets, limits, pulse endpoints, speed/inversion, firmware version, armed/stop state |
| POST | `/arm` | Enable/resume PWM unless physical STOP is pressed |
| POST | `/move` | Set pan and tilt offsets together |
| POST | `/home` | Set both offsets to zero |
| POST | `/jog` | Hold normalized pan/tilt rates; zero rates brake smoothly |
| POST | `/stop` | Cancel trajectory and hold commanded position; latch STOP |
| POST | `/disarm` | Cancel and disable PWM; support camera first |
| POST | `/heartbeat` | Renew an already active command lease; never ARM/resume |
| POST | `/calibration` | Validate and save one complete axis configuration while disarmed |

Every POST requires `X-CAMX-Request: 1`. When `API_TOKEN` is nonempty, it also requires `Authorization: Bearer TOKEN`. An empty token disables authentication and is suitable only for a trusted isolated LAN. HTTP is plaintext; this is local control, not an Internet-facing service. No CORS is enabled. The custom header prevents ordinary cross-origin HTML forms from issuing motor commands. Read-only status and the page are unauthenticated; USB serial is a trusted physical control channel.

`/move` requires `Content-Type: application/json` and exactly two unique numeric fields:

```json
{"pan":15,"tilt":-5}
```

These are **degrees offset from calibrated center**, not increments from the last request. Both targets are accepted together or neither changes. Repeating a request is idempotent. Firmware degrees are commanded estimates, not encoder measurements. Default limits are pan ±60°, tilt ±25°; establish actual safe endpoints with horns removed before assembly. Positive direction depends on your calibration/invert configuration.

```sh
# Set CAMX_TOKEN locally to the same API token; omit Authorization if token is empty.
curl -X POST http://DEVICE_IP/arm \
  -H 'X-CAMX-Request: 1' -H "Authorization: Bearer $CAMX_TOKEN"
curl http://DEVICE_IP/move \
  -H 'X-CAMX-Request: 1' -H "Authorization: Bearer $CAMX_TOKEN" \
  -H 'Content-Type: application/json' -d '{"pan":15,"tilt":-5}'
curl http://DEVICE_IP/status
```

Action POSTs have empty bodies. Success returns HTTP 200 and status JSON. Errors: 400 invalid/missing fields or headers, 401 bad token, 404 unknown route, 405 unsupported method, 408 incomplete request deadline, 409 stopped/disarmed/out-of-range movement, 413 oversized headers/body, 415 incorrect media type. Unknown fields, duplicate fields, numeric strings, NaN/infinity, trailing JSON and partial updates are rejected. JSON field order does not matter. Requests require HTTP/1.0 or 1.1, CRLF headers, and Content-Length for POST; chunked bodies and persistent/pipelined connections are unsupported.

## Press-and-hold velocity control

`POST /jog` is an additional mode; `/move` keeps its original absolute-offset contract. Read `/status` after ARM and send the returned `control_epoch` with a strictly increasing `seq`:

```json
{"pan":0.25,"tilt":-0.25,"epoch":2,"seq":1}
```

Exactly these four fields are required. Pan/tilt are finite normalized rates in [-1, 1], multiplied by each axis's calibrated maximum speed. Epoch and sequence are uint32 integers; sequence must exceed the last accepted value. Epoch in this example is illustrative: always use the device's actual value. Both axes are accepted atomically. The local planner approaches saved limits with a bounded acceleration/jerk braking path. Same-rate refreshes preserve the existing ramp. Jog axes are independent; a stationary axis holds while the other moves.

The client refreshes held rates every **100 ms**. On release it sends the next sequence with `pan:0, tilt:0`; firmware plans a smooth braking trajectory from current commanded velocity and acceleration. Releasing one of two held directions brakes that axis while the other continues. A direction reversal also brakes before reversing. Position readouts must use `pan`/`tilt`, not `pan_target`/`tilt_target`, which represent the planned travel boundary while jogging.

A nonzero jog has a separate **500 ms lease** checked in the servo loop and before accepting a renewal. Its expiry immediately holds position without latching explicit STOP. Status polling and `/heartbeat` cannot renew it. A valid zero-rate release ends this short lease while allowing the planned brake to finish; the ordinary five-second watchdog still applies. Browser pointer cancellation, capture loss, blur, hidden tabs, navigation and disconnect clear held inputs and attempt release. If delivery fails, firmware's lease is the fallback; browser unload delivery is never guaranteed.

STOP, DISARM, ARM, accepted MOVE/HOME, Wi-Fi loss and timeout invalidate the epoch. Delayed commands from an earlier mode cannot revive it. Refresh status and deliberately re-ARM after a safety stop; the client never resumes held input automatically. Sequence exhaustion requires a new ARM epoch, rather than wrapping. Epoch/sequence prevent stale ordering within this control protocol; they do not authenticate clients or establish multi-client ownership. Use the token and one active operator. Firmware seeds an unpredictable nonzero epoch on boot to reduce cross-reboot collisions, without promising cryptographic uniqueness.

The design follows velocity-plus-timeout PTZ practice, using a small JSON HTTP API rather than implementing ONVIF. See the [research and design decisions](jog-design.md).

## Calibration and control lease

`POST /calibration` requires JSON with exactly these eight unique typed fields:

```json
{"axis":0,"center":1500,"low":1400,"high":1600,"minimum":-10,"maximum":10,"invert":false,"speed":5}
```

Axis is integer 0 (pan) or 1 (tilt); center/low/high are integer microseconds, 700–2300, with low < center < high. Minimum must be negative and maximum positive, within ±60° pan / ±25° tilt. Speed is finite 1–60°/s; invert must be a JSON boolean. Unknown/duplicate/missing fields, numeric strings, nonfinite values and trailing content are rejected. Valid settings save only while disarmed; applying them never arms or moves the camera. Use measured physical travel, not default endpoint assumptions.

`POST /heartbeat` has an empty body. It renews the five-second timeout only while already armed, unstopped and with the physical STOP input released. It never resumes after a timeout or disconnect. The rich client exposes this as an optional **Maintain control** setting, off by default and disabled on STOP, disconnect, calibration or a hidden tab.

Build and upload the rich interface's LittleFS image separately from firmware. Static assets under `/control/` are read-only and streamed in the HTTP task; traversal and unknown paths are rejected. Filesystem mount failure leaves the small `/` fallback page available and never autoformats storage. See the [control client guide](control-client.md).

## Timing and safeguards

A separate FreeRTOS HTTP task handles one client at a time, using fixed buffers: 2,048 bytes for headers and 384 bytes for the body. Incomplete requests have a 1.5-second receive deadline. Short mutex-protected operations share motion state; network reads/writes happen outside the lock. Slow clients cannot intentionally block the servo loop through HTTP reads, but may occupy the single HTTP slot. Firmware is not a certified real-time controller.

PWM starts disabled. New-device pulse defaults are 1400/1500/1600 µs; valid saved calibration is retained on upgrade, so inspect it before arming. Each target is approached with bounded acceleration and jerk, up to the calibrated maximum speed. Physical STOP is checked in the loop and again when accepting a move/ARM. STOP retains holding torque. Five seconds without an accepted move, ARM or explicitly enabled heartbeat cancels the trajectory and holds position without latching explicit STOP; status polls and invalid requests do not renew this watchdog. After timeout, refresh status and issue fresh input; no ARM is needed if PWM is still enabled and no explicit STOP is latched. Periodic identical `/move` requests may renew the watchdog for a long movement or an active tracking client. DISARM and power loss may let the camera drop; use a tether and support it first. ARM on first enable assumes center and may jump because SG90 has no feedback.

Serial and HTTP calibration remain disabled while PWM is armed. A complete per-axis calibration is saved as one atomic NVS blob before runtime settings change; prior field-based saved settings remain readable. Calibration cannot exceed the CAD envelope (pan ±60°, tilt ±25°); saved configurations beyond those limits are discarded at boot. There is no firmware face-tracking implementation; a host client may calculate offsets and submit them through this API.

## Verification

`tests/motion_test.cpp` checks movement math and atomic target rejection. `tests/http_test.cpp` tests malformed, oversized and fragmented HTTP/JSON input, duplicate fields, numeric edge cases, truncation and deterministic fuzz cases under AddressSanitizer/UndefinedBehaviorSanitizer. `tests/firmware_ui_test.mjs` exercises the HTML embedded in the firmware against mocked HTTP responses, including bearer authentication, ARM/STOP/DISARM and a combined JSON offset request. CI compiles the ESP32 firmware and runs these suites.

Hardware checks still required: real SSID join and router restart, token rejection, slow-client behavior while moving, physical STOP, disconnect/timeout hold, re-ARM, actual servo calibration and load/temperature. No physical hardware test has been claimed.

Implementation references: [Espressif Wi-Fi API](https://docs.espressif.com/projects/arduino-esp32/en/latest/api/wifi.html) and [ArduinoJson parsing API](https://arduinojson.org/v7/api/json/deserializejson/).

## Smooth trajectories

`POST /move`, `POST /home`, and serial `MOVE` / `HOME` all use the same local jerk-limited S-curve planner. Pan and tilt finish together. Speed remains the calibration maximum velocity in degrees/second. Acceleration is limited to `speed / 0.8` degrees/second² and jerk to `speed / 0.32` degrees/second³. This produces a 1.2-second zero-to-top-speed ramp at default constraints; short moves use lower peaks. A 30° rest-to-rest pan move at 25°/s lasts about 2.4 seconds.

Retargeting begins from the current commanded position, velocity and acceleration rather than resetting the ramp. Duplicate targets keep the existing trajectory. Before committing either target, the planner checks the entire trajectory's analytical position extrema against both saved angle ranges. A trajectory that needs braking beyond these bounds is rejected atomically with HTTP 409; the previous accepted path is retained. A reversal can continue briefly in the old direction while braking, within the saved bounds.

STOP, physical STOP, Wi-Fi loss and watchdog expiry immediately cancel the trajectory and hold the current commanded pulse. DISARM cancels it and disables PWM. The five-second command timeout is unchanged: explicitly renew the heartbeat lease for long movements; status polling does not renew it. Fractional microsecond pulse widths are preserved until the final 16-bit 50 Hz PWM conversion (about 0.305 µs per count), avoiding the earlier whole-microsecond rounding. The absolute `/move` JSON remains compatible; the additional `/jog` contract is described above.

Planner implementation: vendored Ruckig 0.15.3 MIT core, fixed two-axis calculation, no network/cloud component. Native sanitizer tests check speed/acceleration/jerk limits, synchronized arrival, retargeting, duplicate commands, immediate STOP, scheduler stalls, path bounds and 4,000 randomized targets plus 4,000 randomized jog sequences, including release, reversal, limit braking and lease ordering. The default build occupies about 95.4% of the application slot; additional features need flash-size review. A real servo remains an open-loop device; software trajectory smoothness is not proof of physical smoothness.

## Connection holds (firmware 0.5.2)

Jog lease expiry, the five-second command watchdog and detected Wi-Fi loss immediately cancel the planner, hold the current commanded position and invalidate old jog packets. Status reports `connection_paused: true`. They preserve PWM and the existing explicit STOP latch. Repeated loss events do not keep changing the epoch while paused. After status recovery, a fresh MOVE/HOME or a fresh jog with the new epoch clears the connection hold; no ARM request or automatic target replay is needed. A physical STOP, POST /stop, or DISARM remains authoritative and cannot be cleared by reconnecting or issuing a jog. First boot still starts disarmed. Old firmware keeps the former timeout latch behavior and must be upgraded for this change.

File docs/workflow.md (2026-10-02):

# CAMX workflow and design decisions

1. Inspect the user's references. Photos 7/8 are the primary shape specification: stationary rectangular base, ESP32 vertical beside a vertical-axis pan servo, one upright housing a horizontal-axis tilt servo, curved cradle with a camera tripod bolt, and an underside tripod socket. Photos 1–6 show the ESP-WROOM-32 DevKit and SG90-type servos. Photos 9/10 show the square Anker camera. The Insta360, OBSBOT and AVer images are styling/mechanism references, not dimension drawings.
2. Make unknown dimensions explicit in `cad/parameters.json`. Camera model, actual mass/CG, servo clone flange/horn, ESP32 board dimensions, USB-C module and capacitor remain unmeasured. Defaults are estimates. Print the fit coupon before the mechanism.
3. Support pan loads using a 6805 bearing (25 × 37 × 7 mm). The SG90 turns the stock horn, not a printed spline. A removable keeper retains the spindle below the bearing. A fixed outer retainer holds the bearing. The tilt axis lies near camera CG; the user-approved opposite 625 bearing support reduces cantilever loading. Matching 6 mm arm plates and rounded foot supports improve stiffness; this remains an unqualified prototype.
4. Keep the electronics in the stationary base: PCB edge rails, capacitor cup and tie slots, panel USB-C aperture and two flange screw holes, PSU cable entry and strain relief, underside steel 1/4-20 nut with a printed retainer cap. Camera USB remains connected to the host computer with a flexible service loop.
5. Implement PlatformIO firmware with 50 Hz PWM, nonblocking speed limiting, persistent calibration, station Wi-Fi with endless reconnect and authenticated HTTP/browser control, serial commands, latched STOP and PWM disabled on boot. Keep AI tracking on an optional host computer.
6. Generate print-oriented STL and 3MF for each part, assembly STEP/BREP/GLB/3MF, print-layout 3MF, vector SVG/DXF drawings and PNG/JPEG/WebP/SVG images. Validate CAD solids, watertight meshes and swept camera/mechanism clearance. Publish exact CAD geometry to the viewer.
7. Build a static Vite/Three.js viewer and GitHub Pages workflow. Check desktop/mobile layout and part visibility, pan, tilt, explode, wireframe, camera views, downloads and guide links. Generate a downloadable archive and record checks.
8. Physical commissioning: measure hardware, update parameters, print coupon, fit empty mechanism, center servos without horns, assemble and balance, then expand travel only after cable clearance and torque checks. Hardware validation requires the real components.

## Appearance

Matte graphite base and matching full-height side shells, restrained raised pan platform, rounded corners, thin perimeter seam, engraved CAMX wordmark and an amber cradle. The viewer uses an open dark studio canvas with mint controls. Its generated UI concept is a styling reference only: the displayed device and downloadable files are actual CAD. The revised sketch supersedes the earlier asymmetric construction: both sides have matching outer profiles, with an empty passive shell enclosing its bearing. Enclosure corners and horizontal edges are rounded.

## Sources checked

- [Tower Pro SG90](https://towerpro.com.tw/product/sg90-7/): nominal 1.8 kgf·cm stall torque at 4.8 V. This is not a continuous operating rating, and clones differ.
- [Espressif LEDC](https://docs.espressif.com/projects/arduino-esp32/en/latest/api/ledc.html): PWM API. PlatformIO's pinned platform uses Arduino 2.0.17; source includes a version guard for the Arduino 3 API.
- [PlatformIO Espressif releases](https://github.com/platformio/platform-espressif32/releases/tag/v6.12.0): reproducible platform pin.
- [build123d exports](https://build123d.readthedocs.io/en/latest/): installed 0.13.0 signatures were inspected and exports generated locally.
- [Three.js OrbitControls](https://threejs.org/docs/pages/OrbitControls.html) and [GLTFLoader](https://threejs.org/docs/pages/GLTFLoader.html): viewer controls and model loading.
- [GitHub Pages custom workflows](https://docs.github.com/en/pages/getting-started-with-github-pages/using-custom-workflows-with-github-pages): deployment setup.

## Control-client implementation

Three parallel workstreams implemented the SolidJS 2 client, its browser/transport tests and documentation, and the firmware calibration/heartbeat/filesystem API. Integration added a dependency-free localhost LAN bridge, validated asset staging, partition-table-derived filesystem flashing instructions, standalone client downloads and Pages deployment. The client uses SolidJS 2.0.0-rc.13 with exact runtime/compiler pins and a committed lockfile.

The browser never arms on connection or reconnect. STOP cancels queued motion, calibration requires disabled PWM, and the optional heartbeat begins off. Tokens remain in memory. Forty-four client tests, three bridge tests, firmware compilation and sanitizer parser tests passed locally; simulated devices do not replace physical commissioning. Visual references and actual interface previews are in `docs/design/`.

## Smooth motion update

Replaced constant-rate steps with a local fixed-two-axis Ruckig 0.15.3 S-curve planner. Velocity/acceleration are retained on retarget, both axes share finish time, and full-path position extrema gate acceptance. Safety STOP cancels instantly. The upstream MIT core and provenance are vendored for reproducible offline builds; all firmware source bundles include it. Speed calibration/NVS format and movement JSON stay compatible.

## Held remote update

The supplied phone remote references guided a matte, concave four-lobe direction pad with a circular Home key and persistent STOP. Native SVG/CSS geometry renders the control; generated concepts are visual references, not functional backgrounds. Precision controls and calibration remain separate workspaces. See `docs/design/remote-spec.md` for visual decisions.

Three coordinated workstreams extended firmware motion/lease fencing, the SolidJS transport/remote, and tests/research documentation. The protocol uses normalized velocity pairs, 100 ms refresh and a separate 500 ms nonzero-jog lease. A zero-rate release brakes smoothly; missed renewal immediately latches STOP. Epoch/sequence fencing rejects old mode packets. Pointer capture, cancellation, visibility and keyboard lifecycle are covered by regression tests. Research and tradeoffs are documented in [jog-design.md](jog-design.md). Physical validation remains required.

## Final audit fixes and remaining gate

Final review corrected release-error propagation at sequence exhaustion, JSON whitespace validation, current-pose capture after braking and the synchronized-absolute versus independent-jog documentation. CI now runs the client suite against the built production site under `/camx/control/`; development-only Solid timing diagnostics are not treated as production failures. The compatible Python environment passes `pip check`, but its Pillow security upgrade is blocked by the current upstream material-library upper bound. See the [final readiness audit](design/remote-qa.md) for the outstanding dependency and physical commissioning gates.

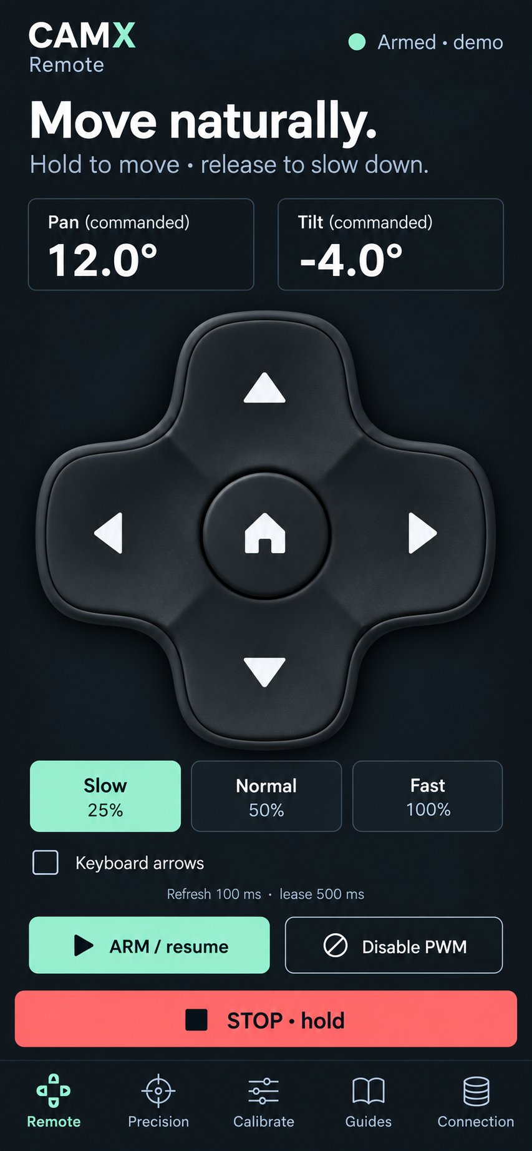
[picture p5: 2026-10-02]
docs/design/remote-mobile-concept.png

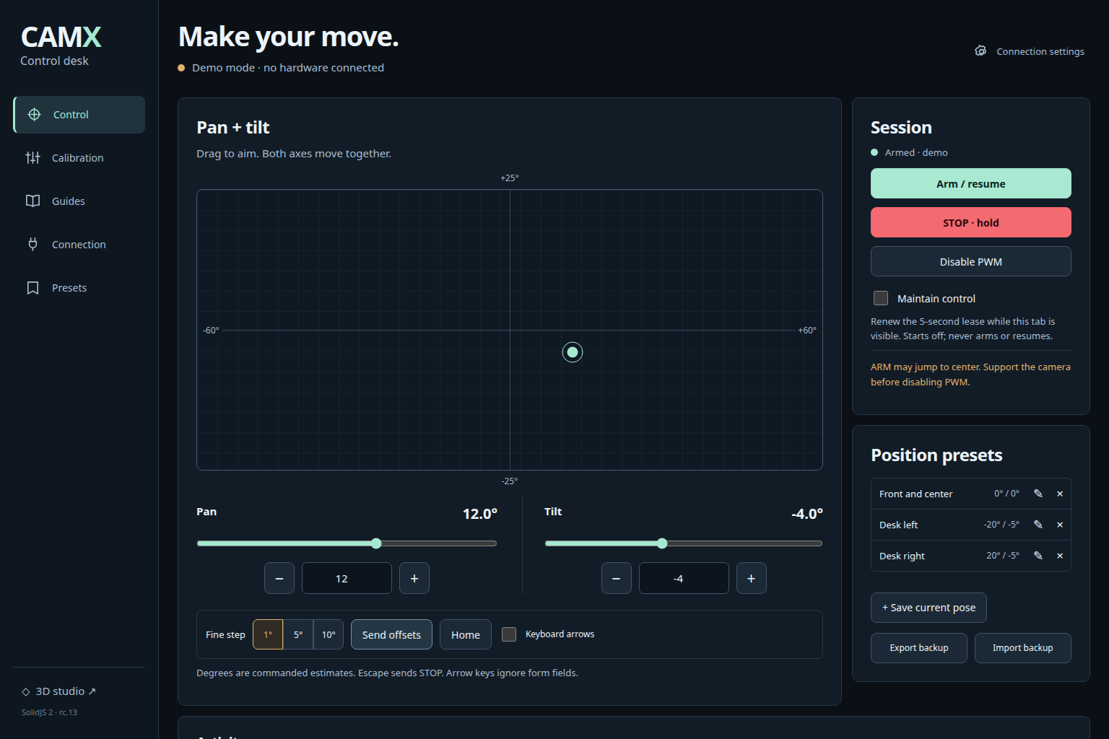
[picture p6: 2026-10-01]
docs/design/control-desktop-preview.png

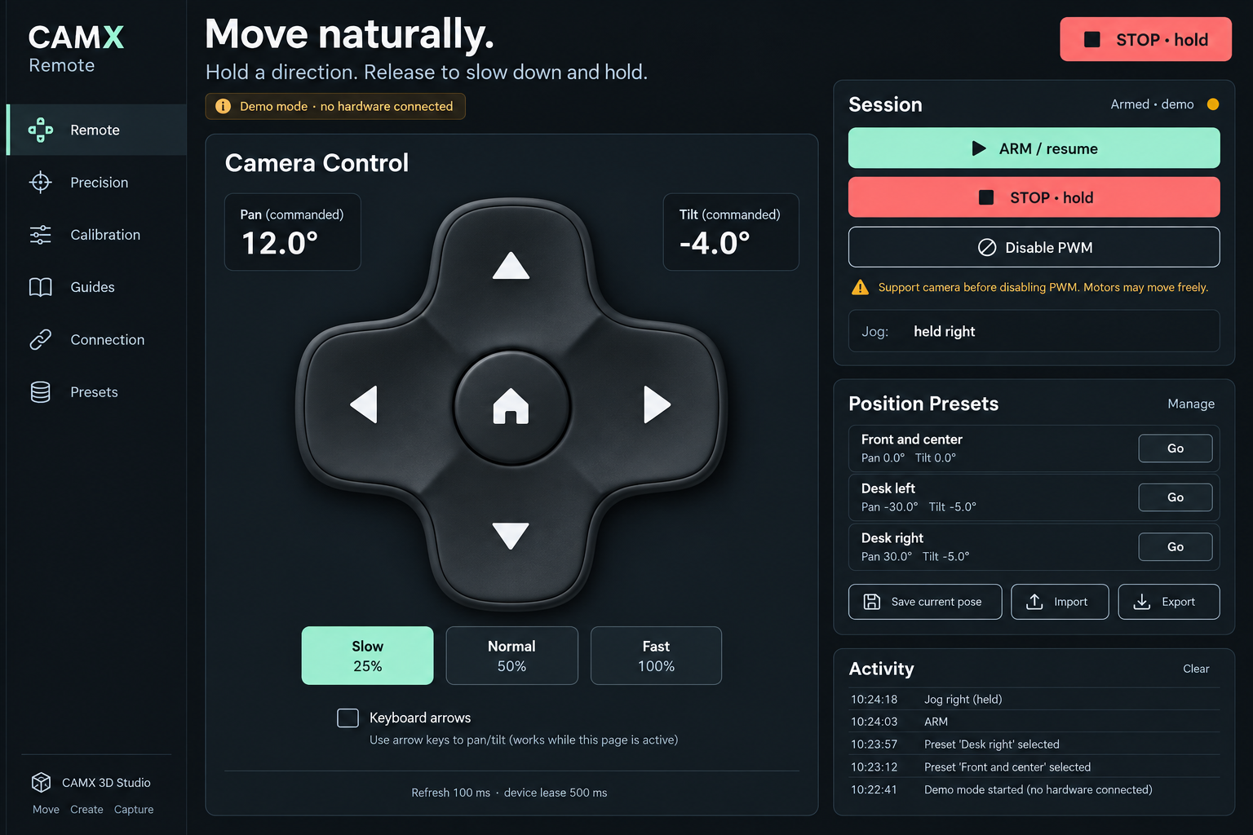
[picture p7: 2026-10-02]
docs/design/remote-concept.png

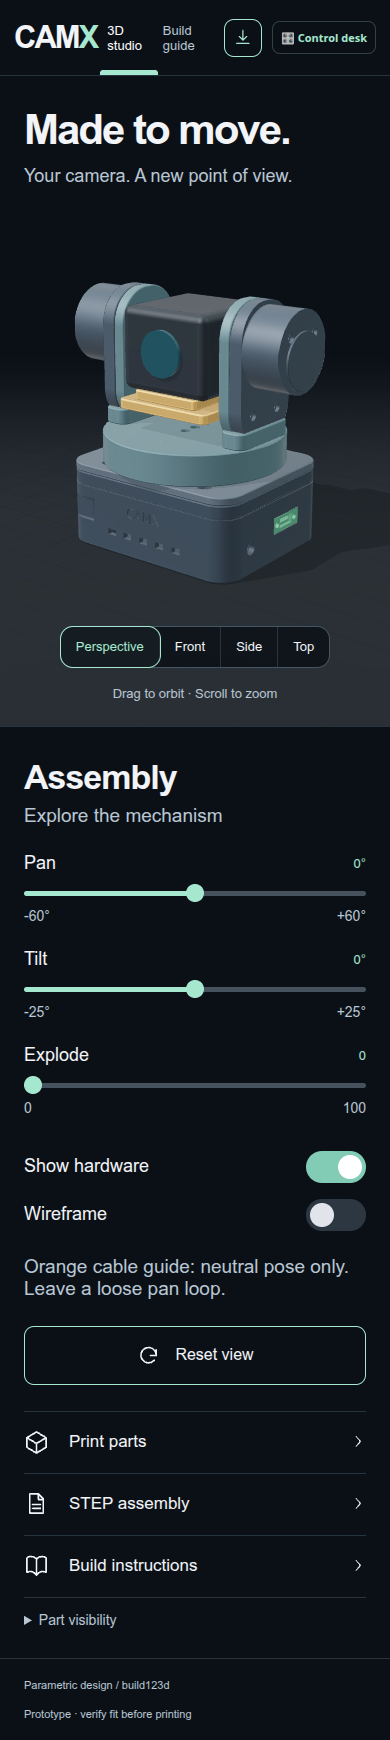
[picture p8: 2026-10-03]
docs/design/viewer-mobile.png

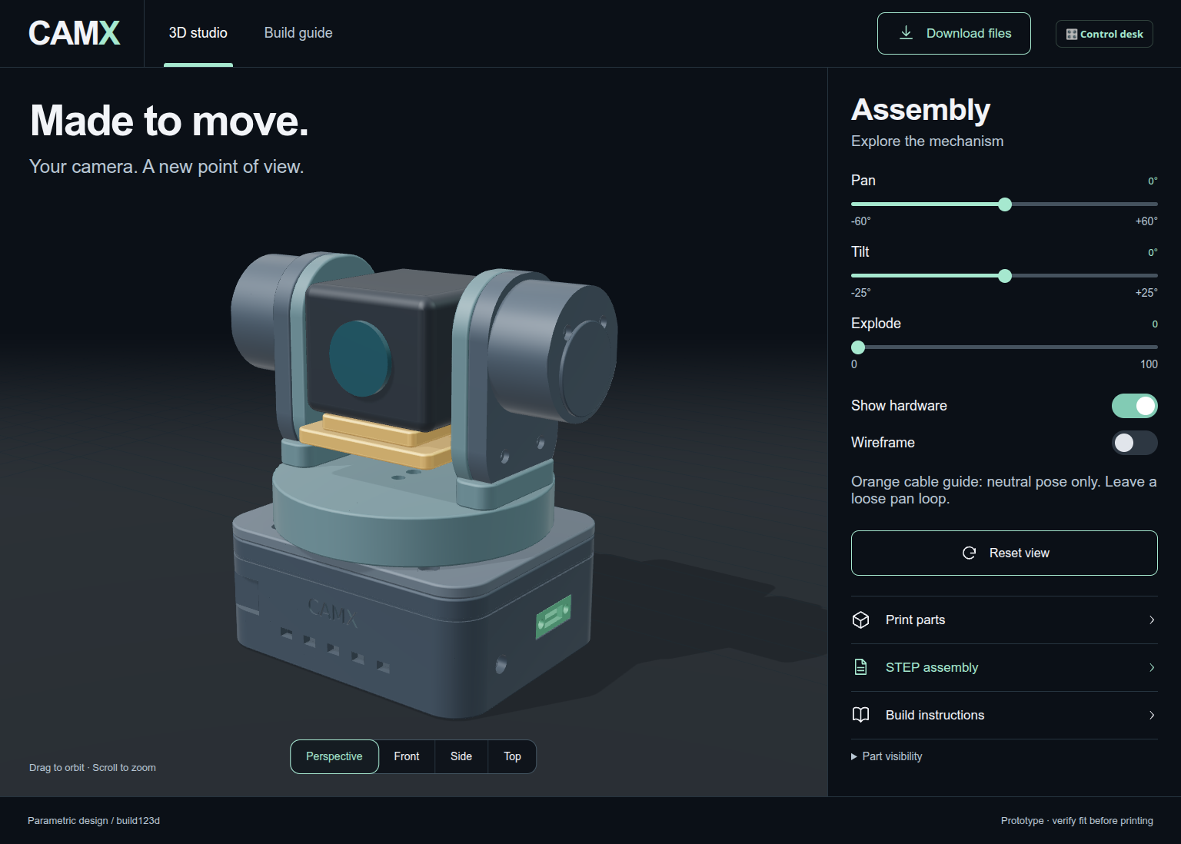
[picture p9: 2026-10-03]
docs/design/viewer-desktop.png

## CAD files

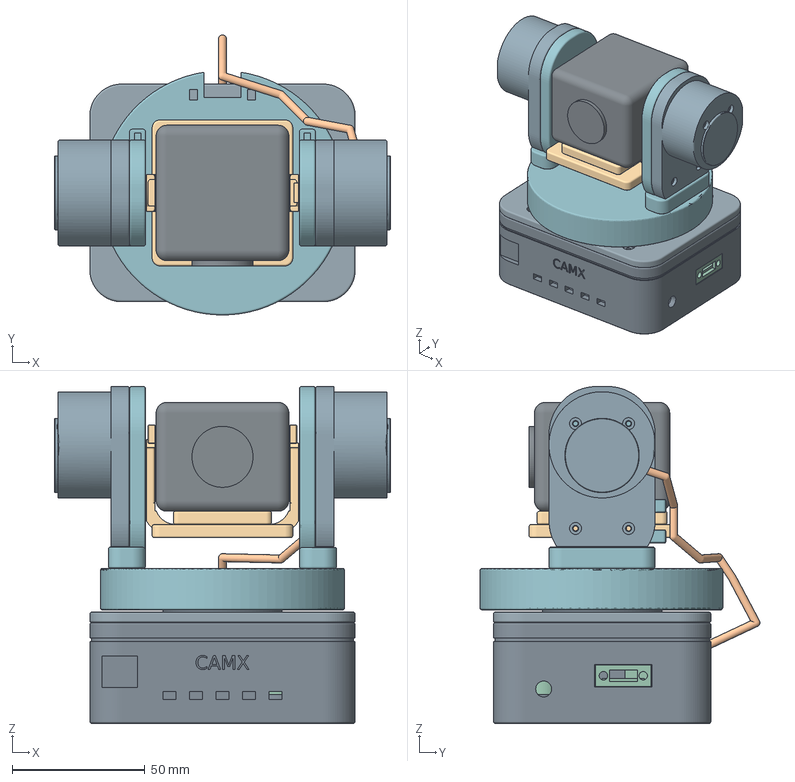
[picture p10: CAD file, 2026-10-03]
exports/assembly/reference_assembly_DO_NOT_PRINT.3mf
126.6 x 105.5 x 127.0 mm
tripod_nut_retainer
base
lid
bearing_retainer
spindle_keeper
drive_arm
pan_arm
tilt_cover
idler_arm
idler_cover
idler_bearing_retainer
camera_cradle
pan_servo
tilt_servo
bearing_6805
esp32_envelope
capacitor_envelope
usb_pcb_envelope
usb_flange_envelope
idler_bearing_625
idler_spacer
idler_outer_washers
idler_axle_M5
idler_jam_nut_M5
camera_envelope
tilt_cable_route
camera_lens

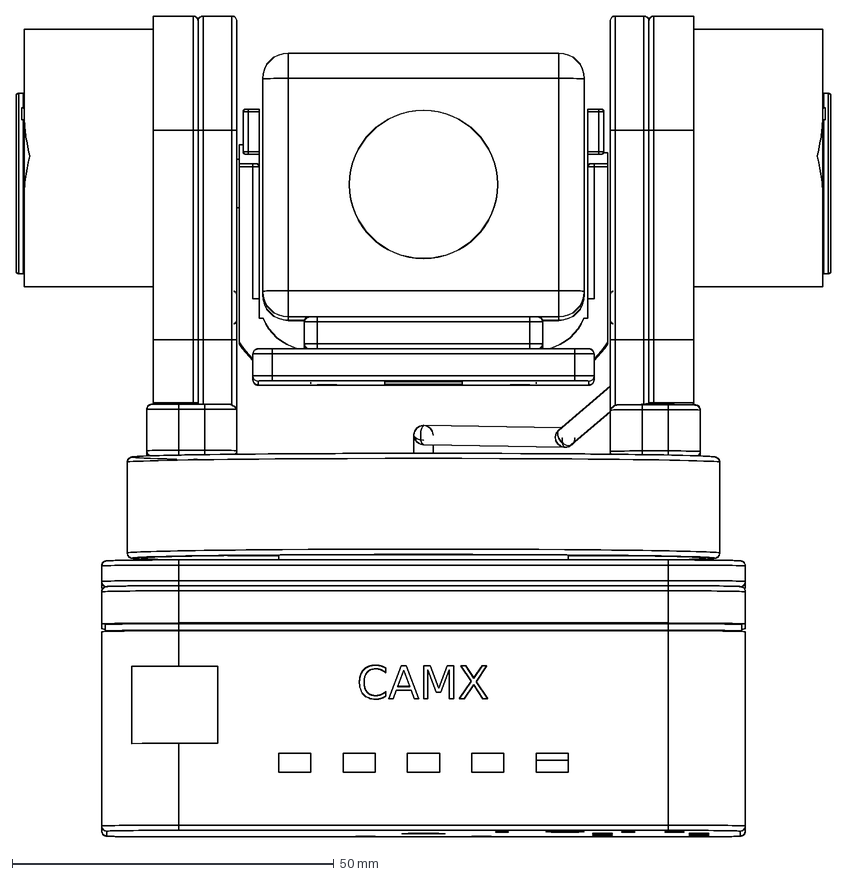
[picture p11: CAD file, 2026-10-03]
exports/drawings/assembly_front.dxf
126.6 x 127.5 mm

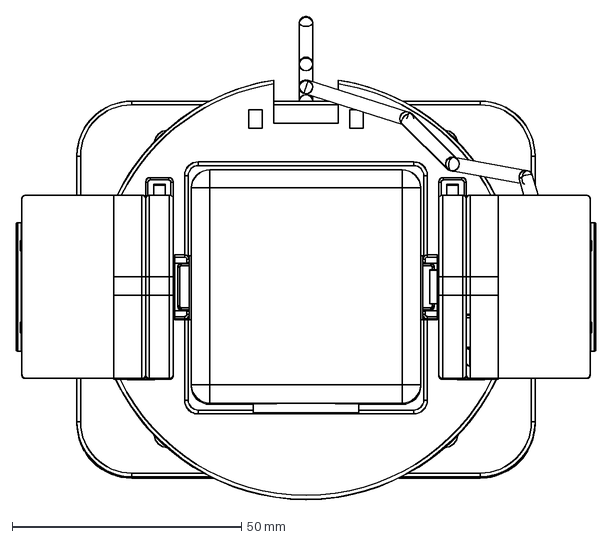
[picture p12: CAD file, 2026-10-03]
exports/drawings/assembly_top.dxf
126.6 x 105.6 mm

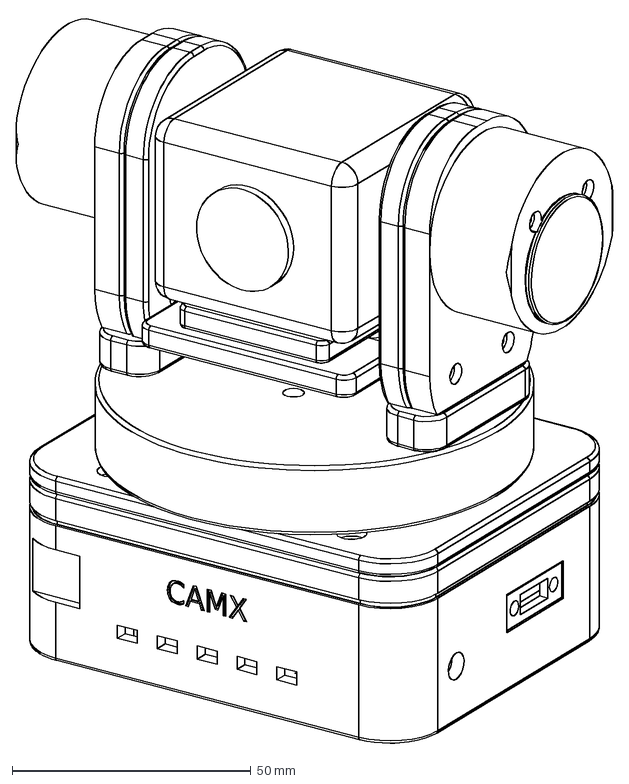
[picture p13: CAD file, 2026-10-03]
exports/drawings/assembly_isometric.dxf
125.0 x 152.6 mm

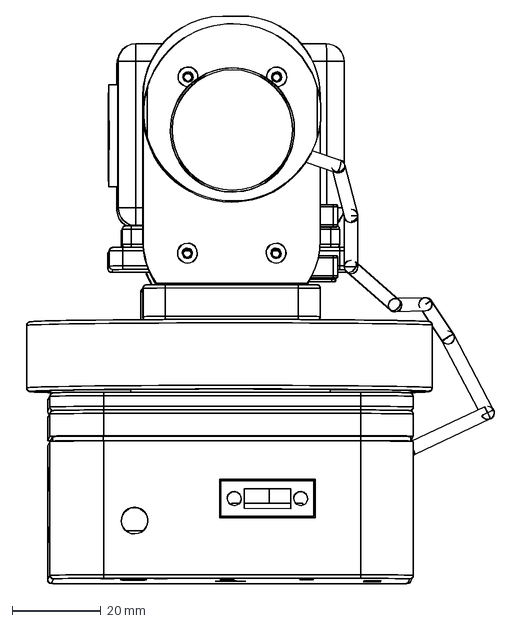
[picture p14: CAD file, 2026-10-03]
exports/drawings/assembly_right.dxf
108.0 x 128.2 mm

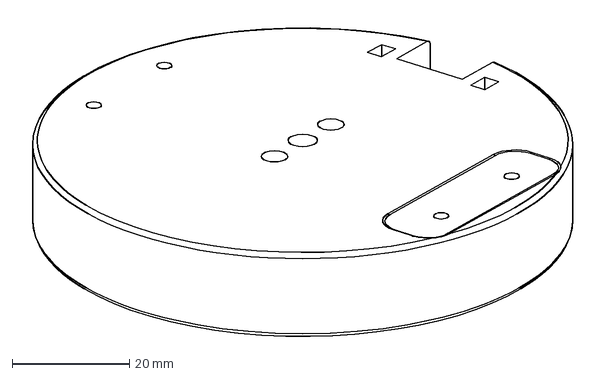
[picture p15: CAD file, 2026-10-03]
exports/drawings/pan_arm.dxf
96.4 x 54.6 mm

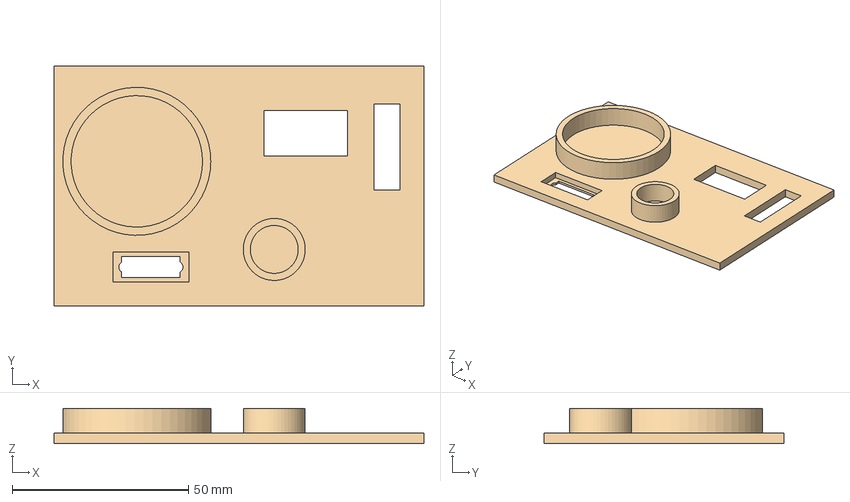
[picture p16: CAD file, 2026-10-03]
exports/parts/fit_coupon.step
105.0 x 68.0 x 10.0 mm

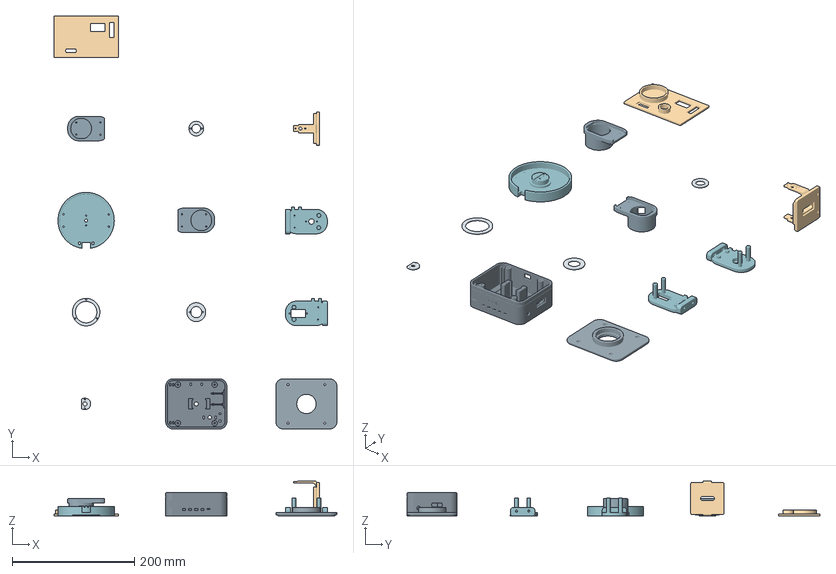
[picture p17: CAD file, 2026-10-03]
exports/assembly/print_layout.3mf
462.5 x 675.0 x 57.2 mm
tripod_nut_retainer
base
lid
bearing_retainer
spindle_keeper
drive_arm
pan_arm
tilt_cover
idler_arm
idler_cover
idler_bearing_retainer
camera_cradle
fit_coupon

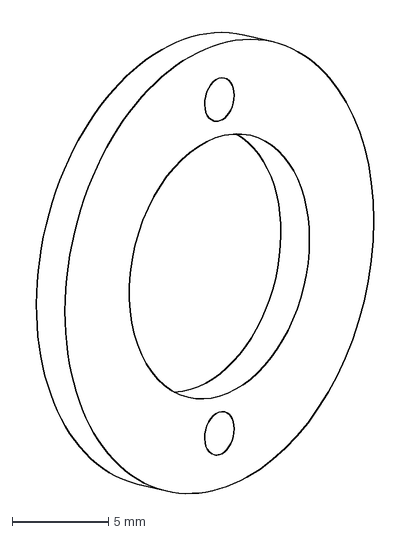
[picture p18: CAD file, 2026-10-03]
exports/drawings/idler_bearing_retainer.dxf
19.1 x 24.9 mm

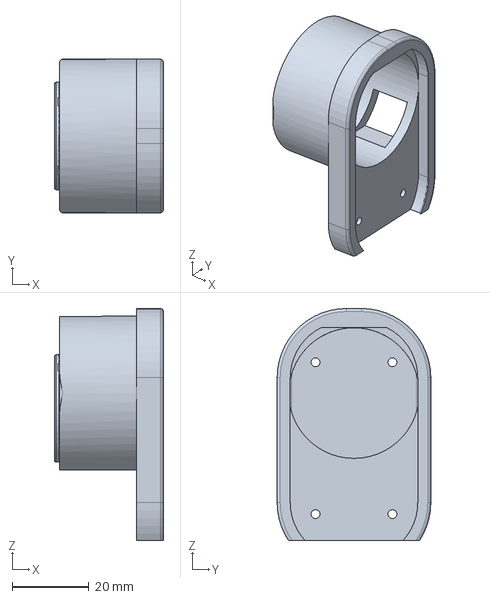
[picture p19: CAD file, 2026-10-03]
exports/parts/idler_cover.step
28.3 x 40.0 x 60.4 mm

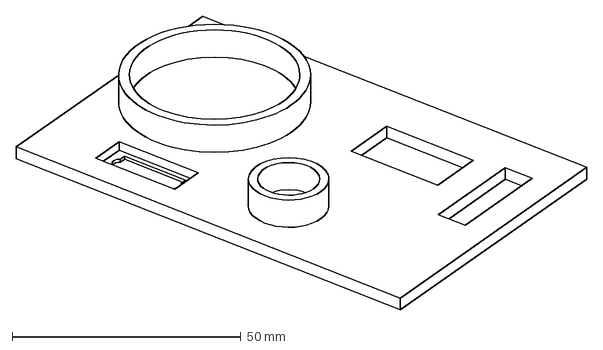
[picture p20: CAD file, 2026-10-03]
exports/drawings/fit_coupon.dxf
124.8 x 64.2 mm

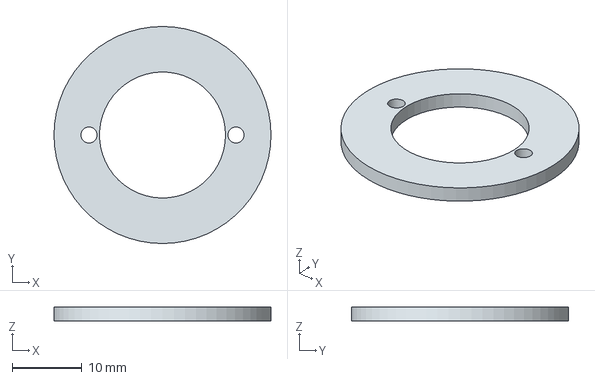
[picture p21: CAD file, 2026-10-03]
exports/parts/spindle_keeper.step
31.0 x 31.0 x 2.00 mm

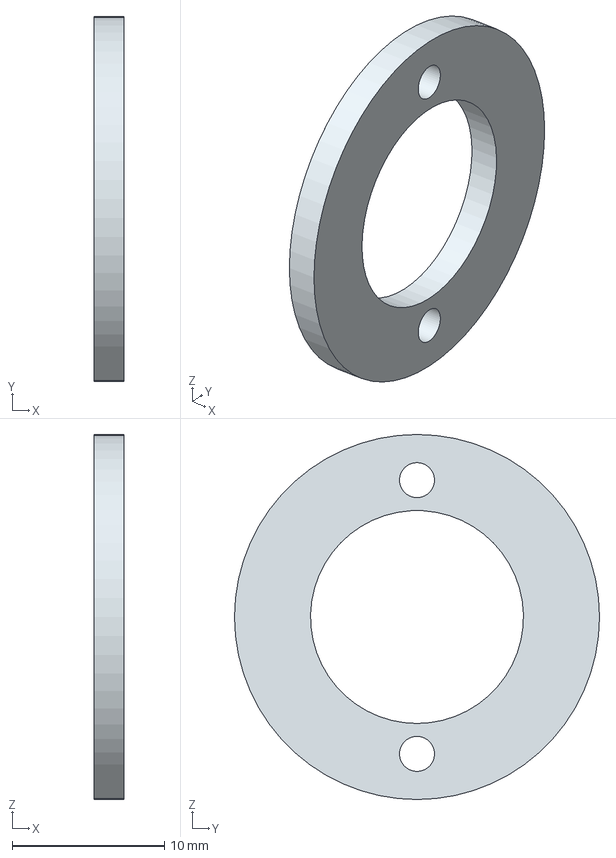
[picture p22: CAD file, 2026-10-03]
exports/parts/idler_bearing_retainer.step
2.00 x 24.0 x 24.0 mm

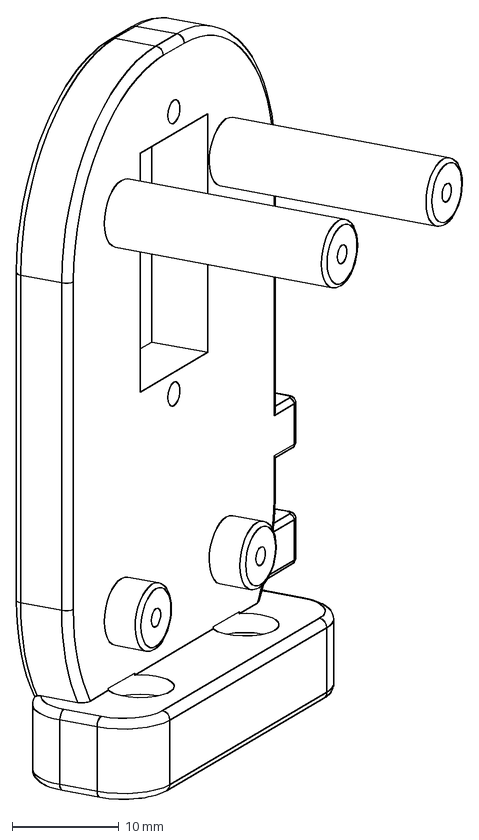
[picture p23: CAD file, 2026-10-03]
exports/drawings/drive_arm.dxf
41.8 x 73.4 mm

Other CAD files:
exports/assembly/camx.step
exports/parts/pan_arm.step
exports/drawings/tilt_cover.dxf
exports/parts/camera_cradle.step
exports/drawings/base.dxf
exports/drawings/bearing_retainer.dxf
exports/drawings/camera_cradle.dxf
exports/drawings/idler_arm.dxf
exports/drawings/idler_cover.dxf
exports/drawings/lid.dxf
exports/drawings/spindle_keeper.dxf
exports/drawings/tripod_nut_retainer.dxf
exports/fasteners/idler_axle_M5x12_FIT_ONLY.3mf
exports/fasteners/idler_axle_M5x12_FIT_ONLY.dxf
exports/fasteners/idler_axle_M5x12_FIT_ONLY.obj
exports/fasteners/idler_axle_M5x12_FIT_ONLY.ply
exports/fasteners/idler_axle_M5x12_FIT_ONLY.step
exports/fasteners/idler_axle_M5x12_FIT_ONLY.stl
exports/fasteners/printed_idler_captive_nut.3mf
exports/fasteners/printed_idler_captive_nut.dxf
exports/fasteners/printed_idler_captive_nut.obj
exports/fasteners/printed_idler_captive_nut.ply
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

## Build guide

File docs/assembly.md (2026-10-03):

# CAMX assembly and commissioning

This is a buildable, dimension-adjustable prototype based on your sketches. It is not physically fit-tested. Use two **positional** SG90 servos; continuous-rotation versions cannot follow angles. The photos appear consistent with a square Anker camera, but do not establish its model or dimensions.

## Measurements before printing

Record webcam width/depth/height including the folded original mounting clip; its mass; tripod thread position and usable insertion depth; CG relative to the screw; cable bend radius. Default camera envelope is **50 × 51 × 41 mm**, **150 g**. The thread slot allows approximately ±8 mm fore/aft adjustment. Measure your particular SG90 body, ears, screw pitch, shaft height and stock horn. The pictured ESP32 has a USB-C port; verify its approximately 58 × 29 mm board fits the rails and left-front access opening. Measure USB flange, hole pitch, PCB overhang, capacitor diameter and height. Defaults are not measurements from photographs.

Edit `cad/parameters.json`, regenerate, and rerun checks. Fit clearance is per radial/side convention indicated in the source; some structural and fastener dimensions are fixed constants and require editing `cad/model.py` for substantially different hardware. The parts are not a universal automatic fit system.

## Bill of materials

| Item | Quantity | Notes |
| --- | ---: | --- |
| ESP32-WROOM-32 DevKit | 1 | Pictured USB-C version; 5 V input verified on actual board |
| Positional SG90-type servo | 2 | Stock spline-matching horns and center screws |
| 6805 bearing | 1 | 25 mm ID × 37 mm OD × 7 mm height |
| 625 bearing | 1 | 5 mm ID × 16 mm OD × 5 mm width, opposite tilt support |
| Printed shoulder axle + printed captive nut | 1 matched pair | Supplied in exports/fasteners; prototype, verify print fit/load |
| Printed outer washer + inner spacer | 2.5 mm washer, 1.4 mm spacer | Supplied in exports/fasteners; contact bearing inner race only |
| M3 × 12 screws | 4 | Both arm feet into platform pilot holes |
| M2 × 8 screws | 2 | Opposite bearing retainer into arm pilot holes |
| M2 nuts | 6 total | Two tilt ear nuts plus four horn attachment nuts; match actual screw lengths |
| Regulated 5 V / 3 A PSU | 1 | Servo power independent of USB programming power |
| 1000 µF electrolytic | 1 | 10 V or higher rating; default 13 mm diameter × 25 mm height |
| Panel USB-C board/module | 1 | User-supplied module; see wiring constraints |
| M3 × 10 screws | 4 | Lid into base pilot holes; do not overtighten |
| M2 × 8 screws | 3 | Bearing outer retainer into lid pilot holes |
| M2 × 6 screws | 4 | Spindle keeper and tripod nut cap into printed spindle pilot holes |
| M2 × 16 screws + nuts | 2 sets | Pan horn-to-platform; verify head recess and approximately 13 mm stack |
| M2 × 8 screws + nuts | 2 sets | Tilt horn-to-cradle; verify stock horn and final stack |
| SG90 ear screws | 4 | Pan stock screws; tilt M2 × 10–12 through-bolts with nuts, verify actual stack |
| M2 × 8 screws | 8 | Matching arm covers into integral standoffs; verify head height |
| M3 screws, nuts and washers | 2 sets | USB flange; length depends on actual flange thickness |
| Steel 1/4-20 UNC hex nut | 1 | ~11.1 mm across flats, ~5.5 mm thick; fits captive base socket |
| 1/4-20 camera screw + washer | 1 | Choose length for approximately 3–4 mm engagement only if camera permits |
| Zip ties / insulating tape / adhesive rubber feet | As needed | Electrical insulation, strain relief and desk grip |
| Normally-open stop button | Optional | GPIO33 to GND, normally high input |

CAMX exports thirteen printable parts: base, tripod_nut_retainer, lid, bearing_retainer, spindle_keeper, pan_arm, tilt_cover, camera_cradle, drive_arm, idler_arm, idler_cover, idler_bearing_retainer, fit_coupon. The reference assembly's hardware shapes are envelopes, not parts to print. Screws, horns and cables are documented but not modeled in full detail.

## Printing

Use PETG for the mechanism, 0.2 mm layers, 4 perimeters, 5 top/bottom layers and ~35–45% infill. The base and lid should print flat; bearing rings and fit coupon flat. The pan platform prints with its upper face down; both arm plates print flat on their inner faces; cradle prints on its side; both matching arm shells print with the closed outer face down. Their raised pivot medallions touch the bed first; add thin supports beneath the surrounding cover face. Exported STL/3MF files already apply these orientations and sit at Z=0. Inspect the slicer preview: local supports may be required under the pan platform/stem, enclosure access openings and cradle transitions. Do not assume a supplied 3MF has printer, material or support settings; it contains geometry in millimetres only. Individual 3MF is preferable to the large print layout on a small bed.

Print `fit_coupon` first: bearing seat, servo cavity, horn pocket, USB flange recess and hole pitch, capacitor cup. Printed holes may need drill/ream finishing. Keep bearing insertion gentle; do not force it into a tight seat. Sand the spindle until it fits the inner race without wobble; nominal spindle is 24.8 mm. Its axial retainers leave nominal 0.2 mm clearance on each side, so confirm the printed assembly rotates freely. The split-free keeper is screwed on after bearing insertion.

## Mechanical assembly

1. Insert the steel 1/4-20 nut from above into the bottom boss. Its flat sides prevent rotation. Check your existing tripod screw does not rise into the servo. The nut sits 1 mm above the underside. Install tripod_nut_retainer over it with two M2 × 6 screws before installing the pan servo. This cap prevents the nut lifting or dropping out.
2. Install the vertical pan servo on the base's two ear towers, shaft upward. Do not install its horn yet. Insert the ESP32 board edges into the vertical side rails; insulate header pins from other hardware. Use tape or a removable foam wedge for longitudinal retention. Secure the USB board and capacitor using ties, leaving PCB pads and capacitor leads insulated.
3. Seat the bearing in the lid against its shoulder and install the thin outer retainer with three screws. The pan spindle enters the inner race from above. Attach the keeper from below with two M2 screws; rotate by hand to confirm it does not rub the lid underside.
4. Fit the actual pan horn in the spindle underside pocket. The design assumes a **24 × 7 × 2 mm straight double-arm horn**, with attachment holes 16 mm apart. Modify the horn parameters/pocket for your supplied horn. Use the original servo center screw, reached through the center of the pan platform, and two M2 × 16 horn-to-print screws reached through the outer access holes, with nuts below the stock horn. Measure the actual approximately 13 mm stack before choosing final screw length; keep screw tips and nuts clear of the servo crown. Do not substitute printed spline teeth. Verify the horn stays flat without distorting the printed stem.
5. Fasten the drive-side plate to the pan platform with two M3 screws. Check it sits flat. Install the tilt servo in the upright from the outward/right side. Its shaft faces toward the camera and its body is enclosed by the removable hood. Servo ears seat on the arm outer face. Use the two ear holes with M2 through-bolts and nuts; the hood is installed last. Clearance and all four hood screw paths should be checked dry before powering.
6. Center both servos using the firmware with horns removed. Support the camera/cradle during every power or PWM disable operation. Set ARM, wait for center pulses, STOP to hold, then fit the pan horn at straight ahead and the tilt horn with the shelf level. Switch off power before completing fastening. A restarted SG90 can jump to its center; smooth motion applies after enabling, not to the unknown startup position.
7. Put the camera mounting screw through the shelf before attaching the cradle, because the space below the shelf is limited. Fit the tilt horn into the outward-facing cradle recess and secure it to the servo spline with its original screw. The screw is reachable from the inner/left side through the hub. Attach the cradle with two horn screws. Some SG90 horns need trimming/drilling to match the coupon; retain enough material around both holes.
8. Fasten the opposite arm to the pan platform with two M3 screws. Seat the 625 bearing in its outside pocket and fit the outer retainer with two M2 screws. Insert the printed shoulder axle from the left through an outer washer stack totalling 2.5 mm, the bearing inner race and a 1.4 mm spacer, into the cradle cheek and matched printed 2.7 mm captive nut. Turn gently by hand until retained; do not torque-tighten or preload: the bearing must rotate freely. The spacer must touch only the inner race and clear the printed shoulder. Confirm the axle tip/nut cannot touch the camera. Do not force the cheek sideways to compensate for a poor fit.
9. Mount the webcam with a steel 1/4-20 screw through the slot. Shelf stack is nominally 10 mm, with a 2.5 mm head recess; washer and camera thread engagement determine screw length (often about 11–13 mm from under head, but **measure your camera**). There is no printed male camera thread. Use a thin grip pad to resist camera rotation. Keep vents/microphones uncovered. Fold/position the factory clip only if it remains clear during tilt.
10. Route the tilt lead through the 12 × 10 mm rear exit in the pivot shell, down the back of the driven arm, and secure it to the two rear tie eyes. Route it across the top of the pan platform to the open 14 mm rear notch. Anchor it using the platform's paired tie slots. Leave a loose external service loop between this rotating anchor and the 12 × 8 mm entry in the stationary base's rear wall. Secure the inside lead using the paired floor slots. Feed the servo connector before closing the housing; confirm its actual size and don't force it. Never place wires in the bearing races, spindle or gap under the rotating cowl. Secure camera USB separately to the cradle rear slots and leave its own relaxed loop to the PC. Check screw-tip clearance and close the covers only after testing the cable route.

## Balance and load

The tilt pivot is at Z=101 mm, with the camera bottom at 80 mm. For a 41 mm-high uniform camera, center height is ~100.5 mm, close to the pivot. Actual CG includes the factory clip, camera screw, printed cradle and cable drag; adjust fore/aft placement in the slot. Calculate gravity torque as `mass_kg × perpendicular_offset_cm` in kgf·cm. For 150 g and a 1 cm offset, static torque is 0.15 kgf·cm before bracket/cable loads. At a 3 cm offset it is 0.45 kgf·cm. Published SG90 1.8 kgf·cm is stall torque, **not continuous torque**. Aim for a well-balanced mechanism with static load below approximately 0.3–0.4 kgf·cm as an engineering starting assumption, then verify temperature/jitter; this is not a manufacturer continuous rating.

The pan bearing supports vertical and overturning loads. Your approved second tilt arm adds a 625 bearing opposite the servo. Both arm plates are 6 mm thick with matching rounded profiles and foot supports. The full-height covers are exact mirrored solids; one contains the tilt servo, the other only the bearing hardware. This reduces cantilever loading but does not remove the SG90's plastic gears/bearing limitations. Secure the base to a tripod or desk fixture: cable pulls can tip a lightweight freestanding unit. Read the [structural review](structural-review.md) and qualify the assembly with a dummy load before installing the camera.

## Wiring

```
Regulated PSU +5 V ── optional rated USB-C input OR direct cable ── +5 V bus
                                                             ├─ ESP32 VIN / 5V
                                                             ├─ pan red
                                                             ├─ tilt red
                                                             └─ capacitor +
PSU GND ───────────────────────────────────────────────────── GND bus
                                                             ├─ ESP32 GND
                                                             ├─ pan brown
                                                             ├─ tilt brown
                                                             └─ capacitor −
ESP32 GPIO18 ── pan orange signal
ESP32 GPIO19 ── tilt orange signal
ESP32 GPIO33 ── optional STOP button ── GND
Webcam USB ── direct to host PC (separate from servo supply)
```

Power and signal diagram

Use short, adequate power wires in a star arrangement. Connect the 1000 **µF** capacitor across the supply near the servo branch; polarity stripe indicates negative. `1000 mF` would mean one farad and is not the intended component. Never power servo red wires from ESP32 3V3 or through the DevKit regulator. A 5 V / 3 A PSU is the starting specification, not proven simultaneous-stall headroom: TowerPro reports up to approximately 2 A per SG90, so two stalled servos plus the ESP32 can exceed 3 A. Measure loaded current and voltage with both axes moving, avoid jams, and verify wiring/current protection. The capacitor helps brief transients; it cannot supply sustained overload current.

The photographed USB-C board's schematic and rating are unknown. The housing provides its flange mounting and insulated PCB supports. The revised panel module is mounted on the right side, as in the new sketch. Default electrical purpose is **power input only**, with D+/D− left unconnected. Verify its VBUS/GND pinout, CC1/CC2 sink resistors, current capability and orientation with documentation/meter before use. USB-C presence alone does not guarantee a 3 A-rated input; a basic breakout with missing CC resistors may not work with a C-to-C source. Use the direct PSU cable/grommet opening if the module is unsuitable. Do not request USB-PD voltage above 5 V.

For flashing, the ESP32's existing USB-C port is reachable through the left-front opening. Avoid connecting two unisolated 5 V sources: many DevKit clones lack suitable power isolation. Safest setup is flash with PSU disconnected and servo red leads disconnected, unplug programming USB, then use the PSU and Wi-Fi. For simultaneous serial and PSU operation, verify the board schematic or use a USB adapter/cable with **VBUS disconnected but data and GND retained**, keeping ESP32 powered by the PSU. The external panel breakout is not wired to the ESP32 UART/data lines. An ESP32-WROOM-32 cannot read the Anker UVC stream through this breakout.

## Firmware and calibration

The rich [SolidJS control client](control-client.md) adds browser calibration, presets, a two-axis aiming pad and guides. Install its separate LittleFS image and open `http://DEVICE_IP/control/`; the small fallback page remains at `/`.

Build: `.venv/bin/pio run -d firmware`. Flash: `.venv/bin/pio run -d firmware -t upload --upload-port /dev/ttyUSB0` (actual device can be `/dev/ttyACM0`). Monitor: `.venv/bin/pio device monitor -b 115200 -p /dev/ttyUSB0`.

### Upload loses communication after switching baud rate

The project uses `upload_speed = 115200` for firmware and filesystem uploads. If esptool identifies the chip and runs its stub but reports `Unable to verify flash chip connection (No serial data received.)` after changing to 460800 baud, first retry at 115200. The compiled image size is not the cause of that serial timeout.

```sh
pio run -d firmware -t upload --upload-port /dev/ttyUSB0
pio run -d firmware -t uploadfs --upload-port /dev/ttyUSB0
```

Close serial monitors, disconnect the external PSU and servo power leads, and use the ESP32 programming USB port with a short data cable directly connected to the computer. If it still fails, try another cable/port. A diagnostic `python -m esptool --chip esp32 --port /dev/ttyUSB0 --baud 115200 flash_id` checks communication without writing flash; run it in the environment containing esptool. If necessary, repeat at 9600 baud. A crystal-frequency warning is a clue to investigate the serial link and board clock, not proof that the physical crystal has the reported frequency. Do not change the firmware clock settings based only on that warning. If communication remains unreliable with isolated USB power and a known-good cable, inspect the board and connections, especially external wiring on flash-related pins. See [Espressif upload troubleshooting](https://docs.espressif.com/projects/esptool/en/release-v4/esp32/troubleshooting.html).

Copy `firmware/include/credentials.example.h` to `firmware/include/credentials.h` (ignored by Git), set `WIFI_SSID`, `WIFI_PASSWORD` and preferably `API_TOKEN`, then rebuild and flash. ESP32 joins your 2.4 GHz network in station mode. Serial prints the assigned IP; open that address from the same LAN. It retries every 10 seconds without blocking the motion loop, holds position and cancels the motion session on detected connection loss, and never resumes motion automatically after reconnect. No setup AP is created. Public binaries have no credentials and require a local build for Wi-Fi use. Configured binaries contain secrets: keep them private. See [HTTP API](firmware-api.md). GitHub Pages only simulates geometry.

Serial uses newline-terminated commands at 115200 baud:

```
STATUS
ARM
MOVE 15 -5
HOME
STOP
ARM
DISARM
CAL 0 1500 1000 2000 -60 60 0 25
CAL 1 1500 1200 1800 -25 25 1 15
```

CAL fields are `axis center_us low_us high_us minimum_deg maximum_deg invert speed_deg_per_s`; axis 0 pan, 1 tilt. Calibration only works while DISARMED and is saved to NVS. Low/center/high must increase, within 700–2300 µs. Limits must straddle zero and remain within the CAD's ±60° pan / ±25° tilt; speed is 1–60°/s. Unsafe saved limits are discarded at boot. New-device default endpoints are conservative 1400/1500/1600 µs for both servos. Valid saved calibration is retained; inspect it before arming after an upgrade. Pulse-to-mechanical-angle varies: start with horns off, use conservative endpoints such as 1400/1500/1600 µs, then expand slowly while measuring. Firmware degrees are estimated normalized commands, **not measured physical angles**. Invert flips pulse direction. A different invert setting may be needed with your actual horn/servo.

STOP cancels the trajectory and holds the current estimated commanded angle. ARM resumes. The hardware button latches STOP while pressed and must be released before ARM. It is a software stop, not a power-cut emergency stop. DISARM removes PWM and may let the camera fall. After 5 seconds without an accepted movement, ARM, or explicit heartbeat command, firmware stops and continues holding. STATUS polls do not reset that timer. Commands outside limits, NaN, missing numbers and oversized serial lines are rejected. No OTA or cloud dependencies are present.

HTTP: GET `/status`; POST `/arm`, `/stop`, `/disarm`, `/home`; POST `/move` with JSON `{"pan":15,"tilt":-5}`. Every POST requires `X-CAMX-Request: 1` and, if configured, `Authorization: Bearer TOKEN`. Both offsets are absolute degrees from calibrated center and are validated together before either target changes. There is no CORS permission to control it from GitHub Pages. Motion control and the public viewer are intentionally separate.

See [the control-client guide](control-client.md) for browser calibration and deployment, and [the HTTP API](firmware-api.md) for `/calibration` and `/heartbeat`.

## GitHub Pages viewer

`cd viewer && npm ci && npm run build` creates `viewer/dist`, including the viewer, CAD downloads, build guide and firmware. Local development: `npm run dev`; serve the output with `npm run preview`. Assets use relative URLs so the site works under `/camx/` or a custom domain without editing a repository name.

Push the project (including `exports`) to your GitHub repository. In **Settings → Pages → Build and deployment → Source**, choose **GitHub Actions**. `.github/workflows/pages.yml` builds and deploys on pushes to main/master or manual runs. The source repository is `worxbend/camx`. Once Pages is enabled, the workflow publishes the viewer on pushes to main/master.

## Check smooth movement under load

Absolute moves ramp velocity and acceleration using a synchronized jerk-limited S-curve; held jogging applies jerk limits independently to each axis. Calibration Speed is a ceiling; reducing it also reduces acceleration and jerk. First test unloaded at 5°/s, then with a balanced camera and secured base. The default pan speed of 25°/s moves 30° in about 2.4 seconds from rest. Observe cable pull, backlash and small-pulse deadband. STOP is immediate and retains torque; DISARM releases it. Long moves still need an explicit heartbeat lease to avoid the five-second watchdog.

### Recessed USB-C flange

The metal flange remains visible from outside but sits 0.2 mm below the right wall. Its PCB and connector body sit inside. The default pocket is 21.6 × 8.6 mm, 2.2 mm deep, for the owner-specified 21 × 8 mm flange and assumed 2 mm thickness. The separate through-opening is **16.6 × 6 mm**, based on the provisional PCB envelope. The fit coupon matches both pocket and opening. Mounting-hole spacing is **15 mm centre-to-centre**, confirmed by the owner. Hole diameter remains provisionally **3.2 mm**; verify the actual diameter, PCB and plate thickness before printing. A local reinforcement leaves 3 mm of backing beneath the flange. Mount with two M3 screws and internal washers/nuts; choose screw length after measuring the actual flange and screw-head profile. Use low-profile heads that remain below the outer wall plane, or verify/countersink the metal flange appropriately. The CAD does not assume countersunk holes in your photographed module.

Measure the module before printing: flange width, height, thickness, hole pitch, PCB depth, and receptacle housing. Update `usb_flange_thickness`, `usb_flange_recess` (at least the flange thickness plus screw-head height if heads protrude), and related parameters. Print the fit coupon first. Do not force the PCB into the pocket; secure it by its edges with insulated ties. Verify a real USB plug seats fully in the recessed socket before final assembly.

### Short side-cover screws

Both side arms now have matching integral Ø6.5 mm standoffs extending across the shell cavity. Each stops 0.3 mm before the outer cover's inner face, with a 1.8 mm pilot drilled 7 mm deep. Use **four M2 × 8 mm screws per cover** (eight total), with heads fitting the Ø4.5 mm recess. The nominal 3 mm shell and 1.8 mm head recess leave 1.2 mm under the head; an 8 mm screw engages approximately 6.5 mm after the 0.3 mm gap. Check your actual head height and printed pilot fit. Tighten gently; use plastic-compatible thread-forming screws where available. These standoffs are built into the arms and need no separate long bolts or spacers.

### Compact redesign

The stationary base is now **100 × 82 × 38 mm**, replacing 144 × 120 × 40 mm: approximately **55% less bounding-box volume** and 53% less footprint. The pan platform shrinks from Ø116 to **Ø92 mm**. Both lower arm shells are only **7 mm deep**, expanding to 27 mm around the tilt pivot where the SG90 body needs room. The complete neutral assembly is **126.6 × 91.5 × 127 mm** (width × depth × height), excluding cable loops and motion sweep; the 100 × 82 mm figure describes the stationary base only. Geometric printed solid volume drops by approximately **34.5%** compared with the previous model; actual slicer consumption depends on infill and supports. The outer shells remain symmetrical; the passive side retains the 625 bearing. Short M2 × 8 screws and the recessed USB-C flange remain.

The camera clearance envelope is now 50 × 51 × 41 mm, using the owner-stated 50 mm camera width. The opening between the trimmed cheeks is 51 mm, leaving 0.5 mm per side for that width. The earlier conservative 55 mm envelope no longer fits this narrowed version. Confirm the actual width including the factory clip before printing; this change does not establish the exact PowerConf model or certify cable and screw-depth fit. The conservative 150 g mass assumption remains.

The ESP32, pan servo, USB board and capacitor are packed in separate regions. The ESP32 antenna edge still needs RF testing because nearby wires and hardware can reduce range. Use adhesive rubber feet, secure the base against cable pulls, and verify tipping with the actual assembly: the smaller footprint reduces stability margin. Do not treat the compact base as a monitor clip. Leave relaxed cable loops outside the pan bearing.

### Tilt-servo cable commissioning

The orange cable in the 3D viewer shows a possible neutral route for the three-conductor tilt-servo lead. It is an illustrative Ø3 mm envelope, not a manufactured harness or proof of clearance during movement. The servo and its arm move together during pan; camera tilt therefore needs no moving lead across the camera's tilt pivot. The external service loop accommodates pan between the rotating platform and stationary electronics.

Start unpowered at centre. Fit a lead long enough to leave a relaxed loop; add a properly insulated three-wire servo extension if the stock lead is short. Use protective sleeving or a soft grommet at printed openings and deburr every edge. Tie the jacket gently, never the individual conductors or connector. Move pan by hand through ±60° and tilt through ±25°: no tension, rubbing, pinching or snagging is acceptable. Start powered testing at reduced speed with a dummy load, then repeat with the camera's USB cable installed. The actual lead exit, plug size, bend radius and loop length must be checked on your SG90.

## Printed opposite-side cradle joint

Use [printed_idler_shoulder_axle](../exports/fasteners/printed_idler_shoulder_axle.stl) with the matching [printed_idler_captive_nut](../exports/fasteners/printed_idler_captive_nut.stl). The paired print thread has a 0.8 mm pitch and 0.15 mm radial allowance; it is not a precision ISO M5 thread and should not be mixed with metal M5 fasteners. The 12 mm under-head axle has a smooth 4.85 mm bearing journal, with the thread confined to the nut end. A 2.5 mm printed outer washer and 1.4 mm printed inner spacer are supplied. Keep the 625 bearing. The cradle and other structural print parts do not need to change for this joint.

Use PETG or appropriate nylon, 0.12 mm layers, 100% infill and at least four walls as initial print settings. The axle STL/3MF lies horizontally so layer paths can run along the shaft; supports are required under the shaft/head. The nut, washer and spacer print flat. Inspect the slicer preview, clean supports and trial-fit the paired thread before assembly. Do not force it or clamp the bearing. Check smooth hand rotation, camera clearance and retention first unloaded, then with a supported dummy load. Geometry is validated, but print tolerances, strength, creep and loaded durability are unverified. Use a camera safety tether and replace cracked or loose parts. The separate older `FIT_ONLY` screw is a legacy metal-screw reference, not this printed joint.

The [printed joint guide](../exports/fasteners/PRINTED_JOINT.md) and [kit ZIP](../exports/fasteners/printed-idler-kit.zip) include the four print files, editable CAD, drawings and preview images.

## Printed-cradle width correction

The cradle is reduced from 67.2 mm to 57.2 mm across its pivot cheeks, exactly 5 mm inward per side. The lower shelf shrinks from 63 mm to 53 mm. Both arm mounting positions move inward by 5 mm so the servo horn and opposite bearing remain aligned. The camera opening is 51 mm for the owner-stated 50 mm body; this is not a fit for the former 55 mm envelope. Pivot cheeks retain about 3.1 mm thickness and the camera-bottom clearance trims the inner elbows. Hole pitches remain unchanged.

The opposite joint uses the 12 mm printed shoulder axle, an outer washer stack totalling 2.5 mm, the 625 bearing, the existing 1.4 mm inner-race spacer and a paired 2.7 mm printed captive nut (8 mm across flats). The nut's outward face contacts the spacer, so the thin inner capture lip is not intended to carry tightening tension. The model leaves about 0.5 mm between the axle tip and the 50 mm camera envelope; actual fastener lengths and washer thickness must be checked. A full-height M5 nut or the old M5 × 16 screw will not fit this compact joint. Use the matched printed pair, not the legacy fit-only screw.

Only **camera_cradle** and **pan_arm** need reprinting for this revision. Boolean comparison of the print poses confirms that both arm plates, both covers, both bearing retainers, spindle keeper, stationary base and lid retain identical solid geometry and can be reused. Their assembly positions move with the new pan-platform mounting holes. The washer, spacer and captive nut must match the new printed joint.

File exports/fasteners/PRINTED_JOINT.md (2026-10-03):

# Printed cradle axle and captive nut

Print both printed_idler_shoulder_axle and printed_idler_captive_nut. They form a matched pair, not a precision ISO M5 thread and not intended for mixing with metal M5 fasteners. No metal screw or nut is needed.

12 mm under-head length; 4.85 mm smooth bearing journal; 8.5 x 3.5 mm head; 0.8 mm paired thread pitch; 0.15 mm radial thread allowance; 8 mm across-flats x 2.7 mm captive nut. Retain the existing 625 bearing, 2.5 mm outer washer stack and 1.4 mm inner-race spacer; matching printed washer and spacer files are included.

PETG or suitable nylon, 0.12 mm layers, 100% infill and at least four walls recommended. Axle STL/3MF is horizontal, requiring supports under the shaft and head; inspect and clean the threads gently. Nut prints flat. Trial-fit the pair away from the mechanism before assembly. Never force a tight printed thread. Slicer/material profiles are not included.

Place the nut in the cradle hex pocket, then insert the axle from the bearing side through washers, bearing and spacer. Turn gently by hand until retained with free rotation; do not torque-tighten or preload the bearing. Check camera clearance. Test first without the camera, then with a supported dummy load. A printed axle has not been load-qualified; use a camera safety tether and replace parts showing cracking, creep, looseness or damaged threads. The former FIT_ONLY file is not this joint.

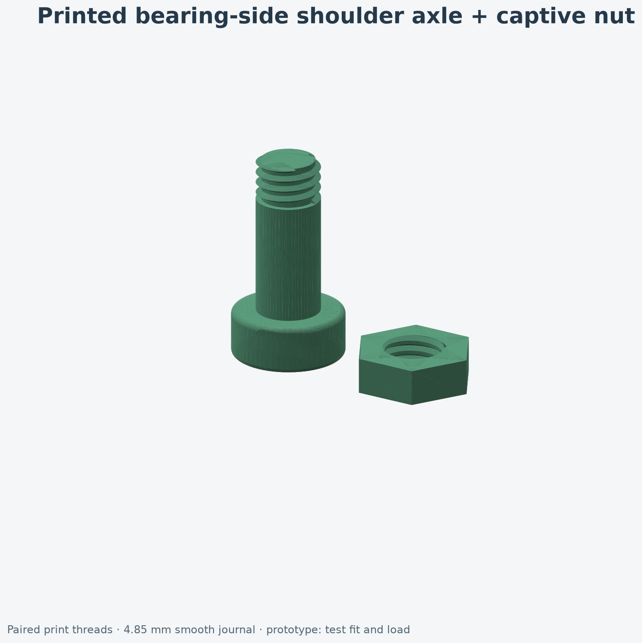
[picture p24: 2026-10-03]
exports/images/printed_idler_joint.jpg

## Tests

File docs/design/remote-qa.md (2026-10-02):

# Remote verification

The production SolidJS client was checked with headless Chromium at 1536 × 1024 and 390 × 844, under a `/control/` deployment path. Browser automation was used because no interactive browser surface was available in this environment.

## Behavior

All 44 client tests passed against the production build. The client suite covers paired held rates, continuous refresh, newer zero release, coalescing and stale-response rejection, lease expiry, pointer capture/cancellation, multi-touch diagonals, held keyboard arrows and focused Space/Enter, focus guards, hidden-page/navigation/disconnect cleanup and deliberate reconnect. Precision, presets, calibration and token privacy remain covered. Older firmware gates held directions while retaining absolute control.

Native sanitizer suites exercise 4,000 randomized absolute commands and 4,000 randomized jog commands, derivatives, release and reversal bounds, limit braking, STOP and epoch/sequence ordering. The bounded HTTP parser passes 30,000 deterministic fuzz cases. Three LAN bridge tests and the embedded fallback page checks pass. ESP32 firmware and matching LittleFS image compile.

## Visual comparison

The selected concepts and actual browser captures were inspected together. The large concave four-lobe pad, circular Home, matte gradient/rim, white arrows, charcoal canvas, mint speed/ARM and coral STOP follow the user's reference. Desktop rail and context column retain the intended hierarchy. On phone, the whole pad, speed choices, ARM/PWM and persistent STOP fit above bottom navigation on the first screen, with no horizontal overflow.

System typography and SVG controls are native; there is no raster text or generated image dependency. Actual positions replace invented concept values. The phone moves ARM above the pad and keyboard details below the fold to keep essential controls reachable. Existing preset rows remain functional rather than copying generated example angles. These intentional deviations are recorded in [the specification](remote-spec.md).

No relevant browser console or page errors were observed in the tested flows. Physical SG90 motion, Wi-Fi latency, task timing under load and loaded stopping distance remain untested. Browser demo motion is illustrative, not evidence of physical servo response. The firmware occupies approximately 95.4% of the default app slot.

Actual previews: [desktop](remote-desktop-preview.png), [phone](remote-mobile-preview.png), [calibration](remote-calibration-preview.png). Generated styling references: [desktop concept](remote-concept.png), [phone concept](remote-mobile-concept.png).

## Final readiness audit

The final audit corrected synchronous release errors at uint32 sequence exhaustion, restricted JSON whitespace to space/tab/CR/LF, and made new “Save current pose” presets capture the latest commanded status, including movement during release braking. Existing preset editing retains its editable values. Absolute moves synchronize arrival; jog axes remain independent. Release source, firmware, filesystem, guides and downloadable archives are rebuilt together for v0.5.1.

Software and print files are ready for controlled prototype commissioning when the recorded checks pass. Physical readiness still requires actual fit, coaxial alignment, balanced dummy-load testing, cable slack, power-source isolation, measured calibration and Wi-Fi/STOP checks. A 50 mm-wide camera fits the nominal 55 mm camera-width envelope; height, depth, folded clip, screw position and usable thread depth must also match. Geometry tests do not establish load or fatigue ratings.

**Open dependency issue:** As checked on 2026-10-02, GitHub reports 13 Pillow alerts (10 high, 3 moderate) against the CAD/image build toolchain's pinned 12.2.0. Pillow 12.3.0 fixes the listed issues, but current build123d 0.13.0 pulls threejs-materials 1.2.x, whose metadata requires Pillow >=12.2.0,<12.3.0. The attempted update failed `pip check`; the compatible pin was restored. An upstream-compatible dependency update or a separately reviewed fork is needed. The ESP32 firmware and browser runtime do not use Pillow. This does not justify claiming a clean security audit; avoid processing untrusted image inputs with that toolchain. [Pillow release notes](https://pillow.readthedocs.io/en/stable/releasenotes/12.3.0.html), [upstream dependency declaration](https://github.com/bernhard-42/threejs-materials/blob/main/pyproject.toml).

The default firmware app slot is approximately 95.4% occupied. Static RAM figures exclude runtime Wi-Fi allocations and task-stack usage; bench checks must measure stack/heap margin and motion planning latency. GPIO STOP is polled by firmware and does not electrically cut motor power.

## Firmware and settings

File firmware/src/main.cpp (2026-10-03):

#include <Arduino.h>
#include <esp_system.h>
#include <atomic>
#include <WiFi.h>
#include <LittleFS.h>
#include <ArduinoJson.h>
#include "http_request.h"
#include "motion_planner.h"
#include "jog_lease.h"
#include "connection_pause.h"
#include <freertos/semphr.h>
#include <Preferences.h>
#include <esp_arduino_version.h>
#include "motion.h"
#include "settings.h"
// Serial and HTTP commands can calculate trajectories; give both task stacks
// extra headroom for the fixed-size solver's nested numerical routines.
SET_LOOP_TASK_STACK_SIZE(16384);
#if __has_include("credentials.h")
#include "credentials.h"
#else
constexpr char WIFI_SSID[]="", WIFI_PASSWORD[]="", API_TOKEN[]="";
#endif

WiFiServer server(80);
SemaphoreHandle_t motionMutex;
struct Guard { Guard(){xSemaphoreTakeRecursive(motionMutex,portMAX_DELAY);} ~Guard(){xSemaphoreGiveRecursive(motionMutex);} };
bool networkWasConnected=false;
bool filesystemReady=false;
std::atomic<bool> networkLost{false};
uint32_t lastReconnect=0;
Preferences prefs;
Axis axes[2];
bool armed=false, stopped=true;
bool connectionPaused=false;
uint32_t lastTick=0, lastCommand=0;
String serialLine;
bool serialOverflow=false;
const int pins[2]={PAN_PIN,TILT_PIN};

void duty(int axis,double pulse) {
  const uint32_t value=servoDutyFor(pulse);
#if ESP_ARDUINO_VERSION_MAJOR >= 3
  ledcWrite(pins[axis],value);
#else
  ledcWrite(axis,value);
#endif
}
MotionPlanner planner;
JogLease jogLease;
void connectionHold(){Guard guard;pauseConnection(planner,axes,jogLease,connectionPaused);}
void halt() {Guard guard;if(!stopped||jogLease.active)jogLease.invalidate();planner.stop(axes); stopped=true;}
void disarm() {Guard guard;jogLease.invalidate();planner.stop(axes);stopped=true;armed=false;duty(0,0);duty(1,0);}
bool arm() {
  Guard guard;
  if(digitalRead(STOP_PIN)==LOW)return false;
  // PWM assumes center on first enable; SG90 has no position feedback.
  if(!armed){for(auto &a:axes){a.current=0;a.target=0;}planner.stop(axes);}
  planner.stop(axes);jogLease.invalidate();armed=true;stopped=false;connectionPaused=false;lastCommand=millis();return true;
}
bool move(float pan,float tilt) {
  Guard guard;
  if(digitalRead(STOP_PIN)==LOW){halt();return false;}
  if(jogLease.expired(millis())){connectionHold();return false;}
  if(!armed || stopped || !std::isfinite(pan) || !std::isfinite(tilt))return false;
  if(!planner.plan(axes,pan,tilt))return false;
  if(digitalRead(STOP_PIN)==LOW){halt();return false;}
  if(jogLease.expired(millis())){connectionHold();return false;}
  jogLease.invalidate();connectionPaused=false;lastCommand=millis();return true;
}
bool jog(double pan,double tilt,uint32_t epoch,uint32_t seq){
  Guard guard;
  if(digitalRead(STOP_PIN)==LOW){halt();return false;}
  if(jogLease.expired(millis())){connectionHold();return false;}
  if(!jogLease.accepts(pan,tilt,epoch,seq,armed,stopped,false))return false;
  if(!planner.jog(axes,pan,tilt))return false;
  if(digitalRead(STOP_PIN)==LOW){halt();return false;}
  if(jogLease.expired(millis())){connectionHold();return false;}
  jogLease.accept(pan,tilt,seq,millis());connectionPaused=false;lastCommand=millis();return true;
}
String status() {
  Guard guard;
  char out[1280];
  snprintf(out,sizeof(out),"{\"armed\":%s,\"stopped\":%s,\"estop\":%s,\"pan\":%.2f,\"tilt\":%.2f,\"pan_target\":%.2f,\"tilt_target\":%.2f,\"pan_min\":%.1f,\"pan_max\":%.1f,\"tilt_min\":%.1f,\"tilt_max\":%.1f,\"pan_center\":%d,\"tilt_center\":%d,\"pan_low\":%d,\"pan_high\":%d,\"tilt_low\":%d,\"tilt_high\":%d,\"pan_speed\":%.1f,\"tilt_speed\":%.1f,\"pan_invert\":%s,\"tilt_invert\":%s,\"firmware\":\"0.5.2\",\"control_epoch\":%u,\"jog_seq\":%u,\"jog_pan\":%.3f,\"jog_tilt\":%.3f,\"jog_active\":%s,\"jog_lease_ms\":500,\"connection_paused\":%s}",
    armed?"true":"false",stopped?"true":"false",digitalRead(STOP_PIN)==LOW?"true":"false",
    axes[0].current,axes[1].current,axes[0].target,axes[1].target,
    axes[0].config.minimum,axes[0].config.maximum,axes[1].config.minimum,axes[1].config.maximum,
    axes[0].config.center,axes[1].config.center,
    axes[0].config.low,axes[0].config.high,axes[1].config.low,axes[1].config.high,
    axes[0].config.speed,axes[1].config.speed,axes[0].config.invert?"true":"false",axes[1].config.invert?"true":"false",unsigned(jogLease.epoch),unsigned(jogLease.sequence),jogLease.pan,jogLease.tilt,jogLease.active?"true":"false",connectionPaused?"true":"false");
  return out;
}
bool number(const String &s,float &value) {
  if(s.length()==0 || s.length()>24)return false;
  char *end;value=strtof(s.c_str(),&end);
  return end!=s.c_str() && *end=='\0' && std::isfinite(value);
}
// One NVS blob per axis makes a complete calibration update atomic. The fixed
// record layout is independent of AxisConfig compiler padding; legacy keys load.
struct __attribute__((packed)) SavedCalibration {
 uint32_t version;int32_t center,low,high;float minimum,maximum,speed;uint8_t invert;
};
void loadConfig(){
  prefs.begin("camx",true);
  for(int i=0;i<2;i++){
    String key=i?"tilt":"pan";
    AxisConfig c=axes[i].config;
    // Field-wise storage avoids struct padding/version dependencies.
    if(prefs.getUInt("version",0)==1){
      c.center=prefs.getInt((key+"c").c_str(),c.center);
      c.low=prefs.getInt((key+"l").c_str(),c.low);c.high=prefs.getInt((key+"h").c_str(),c.high);
      c.minimum=prefs.getFloat((key+"n").c_str(),c.minimum);c.maximum=prefs.getFloat((key+"x").c_str(),c.maximum);
      c.speed=prefs.getFloat((key+"s").c_str(),c.speed);c.invert=prefs.getBool((key+"i").c_str(),c.invert);
    }
    const char *blobKey=i?"tilt2":"pan2";
    SavedCalibration saved{};
    if(prefs.getBytesLength(blobKey)==sizeof(saved) && prefs.getBytes(blobKey,&saved,sizeof(saved))==sizeof(saved) && saved.version==2 && saved.invert<=1){
      AxisConfig candidate;candidate.center=saved.center;candidate.low=saved.low;candidate.high=saved.high;
      candidate.minimum=saved.minimum;candidate.maximum=saved.maximum;candidate.speed=saved.speed;candidate.invert=saved.invert;
      if(axisConfigSafe(i,candidate))c=candidate;
    }
    if(axisConfigSafe(i,c))axes[i].config=c;
  }prefs.end();
}
bool calibrate(int axis,const AxisConfig &c){
  Guard guard;
  if(armed || !axisConfigSafe(axis,c))return false;
  if(!prefs.begin("camx",false))return false;
  const SavedCalibration saved{2,c.center,c.low,c.high,c.minimum,c.maximum,c.speed,uint8_t(c.invert)};
  bool savedOk=prefs.putBytes(axis?"tilt2":"pan2",&saved,sizeof(saved))==sizeof(saved);
  prefs.end();if(!savedOk)return false;
  planner.stop(axes);axes[axis].config=c;axes[axis].current=0;axes[axis].target=0;return true;
}
const char PAGE[] PROGMEM=R"HTML(<!doctype html><html lang="en"><meta charset="utf-8"><meta name="viewport" content="width=device-width"><title>CAMX</title><style>body{font:18px system-ui;background:#17222c;color:#f1f6fa;max-width:650px;margin:30px auto;padding:20px}button{padding:14px;margin:6px;border:0;border-radius:8px;cursor:pointer}input{width:100%;margin:20px 0}#stop{background:#ff6565}pre{white-space:pre-wrap}label{display:block}small{color:#b8cad5}</style><h1>CAMX pan &amp; tilt</h1><p><a href="/control/" style="color:#81eed0">Open full CAMX control studio</a> (requires uploaded filesystem)</p><p>Connect the servo supply and check cable slack before arming.</p><button id="arm">Arm / resume</button><button id="home">Home</button><button id="stop">STOP · hold</button><button id="off">Disable PWM</button><label>Pan <output id="pv">0</output>°<input id="pan" type="range" min="-60" max="60" value="0" step="1"></label><label>Tilt <output id="tv">0</output>°<input id="tilt" type="range" min="-25" max="25" value="0" step="1"></label><label>API token (if configured)<input id="token" type="password" autocomplete="off"></label><p id="state" role="status"></p><small>Disable PWM releases holding torque. Support the camera first. Position values are commanded estimates.</small><details><summary>Calibration (PWM disabled)</summary><p>Serial command: CAL axis center low high min max invert speed. See the assembly guide.</p></details><script>
const $=id=>document.getElementById(id);let ready=false,pending=false,sending=false;
async function post(path,body=''){const r=await fetch(path,{method:'POST',headers:{'Content-Type':'application/json','X-CAMX-Request':'1',...($('token').value?{'Authorization':'Bearer '+$('token').value}:{})},body});if(!r.ok)throw Error(await r.text());return r.json()}
async function action(path){pending=false;try{await post(path);await refresh()}catch(e){$('state').textContent=e.message}}
$('arm').onclick=()=>action('/arm');$('home').onclick=()=>action('/home');$('stop').onclick=()=>action('/stop');$('off').onclick=()=>action('/disarm');
async function send(){if(!pending||sending)return;pending=false;sending=true;try{await post('/move',JSON.stringify({pan:Number($('pan').value),tilt:Number($('tilt').value)}))}catch(e){pending=false;$('state').textContent=e.message}finally{sending=false}}
for(const id of ['pan','tilt'])$(id).oninput=()=>{$('pv').value=$('pan').value;$('tv').value=$('tilt').value;pending=true};setInterval(send,100);
async function refresh(){try{const s=await(await fetch('/status')).json();$('state').textContent=s.estop?'Hardware STOP pressed':!s.armed?'PWM disabled':s.stopped?'Stopped · Arm to resume':'Armed';for(const a of ['pan','tilt']){$(a).min=s[a+'_min'];$(a).max=s[a+'_max'];if(!ready||(!pending&&!sending))$(a).value=s[a+'_target'];$(a).disabled=!s.armed||s.stopped}ready=true;$('pv').value=$('pan').value;$('tv').value=$('tilt').value}catch(e){$('state').textContent='Connection lost'}}setInterval(refresh,1000);refresh();
</script></html>)HTML";
void response(WiFiClient &client,int code,const char *body,const char *type="application/json") {
  const char *reason=code==200?"OK":code==400?"Bad Request":code==401?"Unauthorized":code==404?"Not Found":code==405?"Method Not Allowed":code==409?"Conflict":code==413?"Payload Too Large":code==415?"Unsupported Media Type":"Rejected";
  client.printf("HTTP/1.1 %d %s\r\nContent-Type: %s\r\nContent-Length: %u\r\nConnection: close\r\nCache-Control: no-store\r\nX-Content-Type-Options: nosniff\r\n\r\n",code,reason,type,unsigned(strlen(body)));
  client.print(body);
}
bool serveControl(WiFiClient &client,const char *path){
  if(!safeControlPath(path))return false;
  if(!filesystemReady){response(client,404,"{\"error\":\"client filesystem not uploaded\"}");return true;}
  String filePath=!strcmp(path,"/control/")?"/control/index.html":path;
  File file=LittleFS.open(filePath,"r");
  if(!file || file.isDirectory()){response(client,404,"{\"error\":\"not_found\"}");return true;}
  const char *type=filePath.endsWith(".html")?"text/html; charset=utf-8":filePath.endsWith(".js")?"text/javascript; charset=utf-8":filePath.endsWith(".css")?"text/css; charset=utf-8":filePath.endsWith(".svg")?"image/svg+xml":filePath.endsWith(".png")?"image/png":filePath.endsWith(".woff2")?"font/woff2":"application/octet-stream";
  client.printf("HTTP/1.1 200 OK\r\nContent-Type: %s\r\nContent-Length: %u\r\nConnection: close\r\nCache-Control: no-cache\r\nX-Content-Type-Options: nosniff\r\n\r\n",type,unsigned(file.size()));
  uint8_t buffer[1024];uint32_t started=millis();
  while(file.available() && client.connected() && uint32_t(millis()-started)<5000){
    size_t count=file.read(buffer,sizeof(buffer)),sent=0;
    while(sent<count && client.connected() && uint32_t(millis()-started)<5000){
      size_t written=client.write(buffer+sent,count-sent);if(!written){vTaskDelay(pdMS_TO_TICKS(1));continue;}sent+=written;
    }
    vTaskDelay(pdMS_TO_TICKS(1));
  }
  file.close();return true;
}
void route(WiFiClient &client,const HttpRequest &r) {
  if(!strcmp(r.method,"GET")) {
    if(serveControl(client,r.path))return;
    if(!strcmp(r.path,"/")){response(client,200,PAGE,"text/html; charset=utf-8");return;}
    if(!strcmp(r.path,"/status")){response(client,200,status().c_str());return;}
    response(client,404,"{\"error\":\"not_found\"}");return;
  }
  if(strcmp(r.method,"POST")){response(client,405,"{\"error\":\"method_not_allowed\"}");return;}
  // Custom header prevents cross-origin HTML form requests; no CORS is exposed.
  if(strcmp(r.intent,"1")){response(client,400,"{\"error\":\"X-CAMX-Request: 1 required\"}");return;}
  if(API_TOKEN[0] && String(r.authorization)!=String("Bearer ")+API_TOKEN){response(client,401,"{\"error\":\"unauthorized\"}");return;}
  bool ok=false;
  if(!strcmp(r.path,"/move")){
    if(strcmp(r.contentType,"application/json")){response(client,415,"{\"error\":\"application/json required\"}");return;}
    float pan,tilt;
    if(!parseMove(r.body,pan,tilt)){response(client,400,"{\"error\":\"expected numeric pan and tilt only\"}");return;}
    ok=move(pan,tilt);
  }else if(!strcmp(r.path,"/jog")){
    if(strcmp(r.contentType,"application/json")){response(client,415,"{\"error\":\"application/json required\"}");return;}
    double pan,tilt;uint32_t epoch,seq;
    if(!parseJog(r.body,pan,tilt,epoch,seq)){response(client,400,"{\"error\":\"expected normalized pan/tilt and uint32 epoch/seq\"}");return;}
    ok=jog(pan,tilt,epoch,seq);
  }else if(!strcmp(r.path,"/calibration")){
    if(strcmp(r.contentType,"application/json")){response(client,415,"{\"error\":\"application/json required\"}");return;}
    int axis;AxisConfig config;
    if(!parseCalibration(r.body,axis,config)){response(client,400,"{\"error\":\"invalid calibration schema or limits\"}");return;}
    ok=calibrate(axis,config);
  }else{
    if(r.body[0]){response(client,400,"{\"error\":\"action body must be empty\"}");return;}
    if(!strcmp(r.path,"/arm"))ok=arm();
    else if(!strcmp(r.path,"/stop")){halt();ok=true;}
    else if(!strcmp(r.path,"/disarm")){disarm();ok=true;}
    else if(!strcmp(r.path,"/home"))ok=move(0,0);
    else if(!strcmp(r.path,"/heartbeat")){
      Guard guard;if(jogLease.expired(millis()))connectionHold();ok=controlLeaseAllowed(armed,stopped,digitalRead(STOP_PIN)==LOW);
      if(ok)lastCommand=millis();
    }
    else{response(client,404,"{\"error\":\"not_found\"}");return;}
  }
  response(client,ok?200:409,ok?status().c_str():"{\"error\":\"motion rejected: check arm, stop and limits\"}");
}
void httpTask(void*) {
  // Fixed request buffers and a deadline bound slow/oversized requests before JSON parsing.
  bool listening=false;
  for(;;){
    if(WiFi.status()!=WL_CONNECTED){if(listening){server.end();listening=false;}vTaskDelay(pdMS_TO_TICKS(20));continue;}
    if(!listening){server.begin();listening=true;Serial.print("HTTP ready: http://");Serial.println(WiFi.localIP());}
    WiFiClient client=server.available();
    if(!client){vTaskDelay(pdMS_TO_TICKS(2));continue;}
    client.setTimeout(1000);
    HttpRequest r;uint32_t started=millis();
    while(client.connected() && !r.done && !r.error && uint32_t(millis()-started)<1500){
      for(int n=0;n<128 && client.available() && !r.done && !r.error;n++)r.feed(char(client.read()));
      vTaskDelay(pdMS_TO_TICKS(1));
    }
    if(r.error)response(client,r.error,"{\"error\":\"invalid or oversized HTTP request\"}");
    else if(r.done)route(client,r);
    else response(client,408,"{\"error\":\"request timeout\"}");
    client.stop();
  }
}
void command(String line){
 line.trim();bool ok=false;
 if(line=="STATUS"){Serial.println(status());return;}
 if(line=="ARM")ok=arm();else if(line=="STOP"){halt();ok=true;}
 else if(line=="DISARM"){disarm();ok=true;}else if(line=="HOME")ok=move(0,0);
 else if(line.startsWith("MOVE ")){
   int space=line.indexOf(' ',5);float p,t;
   if(space>5)ok=number(line.substring(5,space),p)&&number(line.substring(space+1),t)&&move(p,t);
 }else if(line.startsWith("CAL ")){
   // Require exactly nine fields; reject trailing junk and fractional integer fields.
   float fields[8];int start=4;bool parsed=true;
   for(int i=0;i<8;i++){int end=line.indexOf(' ',start);if(i==7)end=line.length();if(end<0 || !number(line.substring(start,end),fields[i])){parsed=false;break;}start=end+1;}
   if(parsed && start==int(line.length())+1 && fields[0]>=0 && fields[0]<=1 && fields[0]==floorf(fields[0]) && fields[1]==floorf(fields[1]) && fields[2]==floorf(fields[2]) && fields[3]==floorf(fields[3]) && fields[1]>=700 && fields[1]<=2300 && fields[2]>=700 && fields[2]<=2300 && fields[3]>=700 && fields[3]<=2300 && (fields[6]==0 || fields[6]==1)){
     AxisConfig c;c.center=int(fields[1]);c.low=int(fields[2]);c.high=int(fields[3]);c.minimum=fields[4];c.maximum=fields[5];c.invert=fields[6];c.speed=fields[7];ok=calibrate(int(fields[0]),c);
   }
 }
 if(ok)Serial.println(status());else Serial.println("ERR rejected; STATUS, ARM, STOP, DISARM, HOME, MOVE pan tilt, CAL axis center low high min max invert speed");
}
void setup(){
 motionMutex=xSemaphoreCreateRecursiveMutex();
 if(!motionMutex){while(true)delay(1000);}
 Serial.begin(115200);pinMode(STOP_PIN,INPUT_PULLUP);
 axes[1].config.minimum=-25;axes[1].config.maximum=25;axes[1].config.speed=15;
 loadConfig();
 for(int i=0;i<2;i++){
#if ESP_ARDUINO_VERSION_MAJOR >= 3
  if(!ledcAttach(pins[i],50,16)){Serial.println("PWM init failed");while(true)delay(1000);}
#else
  ledcSetup(i,50,16);ledcAttachPin(pins[i],i);
#endif
  duty(i,0);
 }
 filesystemReady=LittleFS.begin(false);
 WiFi.onEvent([](WiFiEvent_t event){if(event==ARDUINO_EVENT_WIFI_STA_DISCONNECTED || event==ARDUINO_EVENT_WIFI_STA_LOST_IP)networkLost.store(true);});
 WiFi.persistent(false);WiFi.mode(WIFI_STA);WiFi.setHostname("camx");WiFi.setAutoReconnect(true);
 if(WIFI_SSID[0])WiFi.begin(WIFI_SSID,WIFI_PASSWORD);
 else Serial.println("Wi-Fi unconfigured: copy credentials.example.h to credentials.h and rebuild.");
 // Wi-Fi radio is active: seed a nonzero boot epoch before exposing HTTP.
 // This fences delayed packets from an earlier boot (not an authentication token).
 jogLease.seed(esp_random());
 if(xTaskCreatePinnedToCore(httpTask,"camx-http",16384,nullptr,1,nullptr,0)!=pdPASS){Serial.println("HTTP task failed; PWM remains disabled");while(true)delay(1000);}
 Serial.println("CAMX ready, PWM DISABLED. Waiting for Wi-Fi; STATUS works over serial.");lastTick=millis();
}
void loop(){
 // Check before network/serial handling; a pressed switch latches STOP, keeping torque.
 if(digitalRead(STOP_PIN)==LOW)halt();
 const bool connected=WiFi.status()==WL_CONNECTED;
 if(networkLost.exchange(false) || (networkWasConnected && !connected))connectionHold();
 networkWasConnected=connected;
 uint32_t networkNow=millis();
 if(!connected && WIFI_SSID[0] && uint32_t(networkNow-lastReconnect)>=10000){lastReconnect=networkNow;WiFi.reconnect();}
 for(int count=0;count<64 && Serial.available();count++){
  char c=Serial.read();if(c=='\r')continue;
  if(c=='\n'){if(serialOverflow)Serial.println("ERR line too long");else command(serialLine);serialLine="";serialOverflow=false;}
  else if(serialLine.length()<160 && !serialOverflow)serialLine+=c;
  else {serialOverflow=true;serialLine="";}
 }
 {Guard guard;
 uint32_t now=millis();if(jogLease.expired(now))connectionHold();if(armed && !stopped && !connectionPaused && uint32_t(now-lastCommand)>COMMAND_TIMEOUT_MS)connectionHold();
 if(uint32_t(now-lastTick)>=20){float dt=uint32_t(now-lastTick)/1000.0f;lastTick=now;
   if(digitalRead(STOP_PIN)==LOW)halt();
   if(armed){planner.tick(axes,dt);for(int i=0;i<2;i++)duty(i,pulseFor(axes[i].current,axes[i].config));}
 }
 }
 delay(1);
}

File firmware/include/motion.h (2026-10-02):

#pragma once
#include <cmath>
#include <algorithm>
#include <cstdint>
struct AxisConfig {
  // Conservative startup envelope; measure actual travel before expanding.
  int center = 1500, low = 1400, high = 1600;
  float minimum = -60, maximum = 60, speed = 25;
  bool invert = false;
  bool valid() const {
    return low >= 700 && high <= 2300 && low < center && center < high &&
      std::isfinite(minimum) && std::isfinite(maximum) && std::isfinite(speed) &&
      minimum >= -80 && maximum <= 80 && minimum < 0 && maximum > 0 &&
      speed >= 1 && speed <= 60;
  }
};
inline float bounded(float v, float lo, float hi) {return std::max(lo, std::min(hi,v));}
inline double pulseFor(double angle, const AxisConfig &c) {
  double a = std::max(double(c.minimum),std::min(double(c.maximum),angle));
  double fraction = a >= 0 ? a / c.maximum : a / -c.minimum;
  if (c.invert) fraction = -fraction;
  return c.center + fraction * (fraction >= 0 ? c.high-c.center : c.center-c.low);
}
// Keep fractional microseconds until the final 16-bit, 50 Hz PWM conversion.
inline uint32_t servoDutyFor(double pulse) {
  if(!std::isfinite(pulse) || pulse<=0)return 0;
  return uint32_t(std::lround(std::min(pulse,20000.0)*65535.0/20000.0));
}
struct Axis {
  AxisConfig config;
  double current = 0, target = 0, velocity = 0, acceleration = 0;
  void stop() {target=current;velocity=0;acceleration=0;}
};

// Validate both axes before changing either target. Repeated offsets are idempotent.
inline bool setTargets(Axis (&axes)[2],float pan,float tilt){
  const float values[2]={pan,tilt};
  for(int i=0;i<2;i++)if(!std::isfinite(values[i]) || values[i]<axes[i].config.minimum || values[i]>axes[i].config.maximum)return false;
  for(int i=0;i<2;i++)axes[i].target=values[i];
  return true;
}

inline bool axisConfigSafe(int axis,const AxisConfig &c){
  if(axis<0||axis>1||!c.valid())return false;
  const float limit=axis==0?60.0f:25.0f;
  return c.minimum>=-limit && c.maximum<=limit;
}

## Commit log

2026-10-01 Build CAMX camera pan-tilt firmware, printable CAD and 3D studio
    [assembly_front.dxf, assembly_isometric.dxf, assembly_right.dxf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]
2026-10-01 Add two-sided tilt bearing, rounded surfaces, release pipeline and structural review
    [assembly_front.dxf, assembly_isometric.dxf, assembly_right.dxf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]
2026-10-01 Capture static CAD frames for reliable headless browser screenshots
2026-10-01 Revamp CAMX as a symmetrical modular U-yoke with mirrored side pods
    [assembly_front.dxf, assembly_isometric.dxf, assembly_right.dxf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]
2026-10-01 Harden ESP32 firmware with resilient station Wi-Fi and atomic JSON movement API
2026-10-01 Add SolidJS 2 control desk, calibration API and deployable client
2026-10-02 Fix final audit edge cases and document commissioning limits
    [build_release.py, main.cpp]
2026-10-02 Recess exterior USB-C flange into reinforced base wall
    [assembly_front.dxf, assembly_isometric.dxf, assembly_right.dxf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]
2026-10-02 Add integral cover standoffs for short M2 screws
    [assembly_front.dxf, assembly_isometric.dxf, assembly_right.dxf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]
2026-10-02 Compact camera assembly and pack electronics around component envelopes
    [assembly_front.dxf, assembly_isometric.dxf, assembly_right.dxf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]
2026-10-02 Add complete tilt-servo cable passages and neutral routing guide
    [assembly_front.dxf, assembly_isometric.dxf, assembly_right.dxf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]
2026-10-02 Correct measured USB plate size and pitch; regenerate all outputs
    [assembly_front.dxf, assembly_isometric.dxf, assembly_right.dxf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]
2026-10-03 Regenerate CAD exports and add opposite-side axle fit model
    [assembly_front.dxf, assembly_isometric.dxf, assembly_right.dxf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]
2026-10-03 Hold through transport outages without requiring re-arm
2026-10-03 Use Normal jog speed and explain measured pulse calibration
2026-10-03 Narrow cradle 5 mm per side and align reusable arms
    [assembly_front.dxf, assembly_isometric.dxf, assembly_right.dxf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]
2026-10-03 Add paired printed cradle axle nut washer and spacer
    [assembly_front.dxf, assembly_isometric.dxf, assembly_right.dxf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]
2026-11-11 [ImgBot] Optimize images (#2)
    *Total -- 14,805.97kb -> 11,148.40kb (24.7%)
    /exports/images/front.png -- 355.65kb -> 157.73kb (55.65%)
    /exports/images/assembled.png -- 667.88kb -> 313.28kb (53.09%)
    /exports/images/rear.png -- 692.70kb -> 324.98kb (53.08%)
    /exports/images/structure.png -- 640.81kb -> 302.24kb (52.83%)
    /exports/images/exploded.png -- 662.03kb -> 317.75kb (52%)
    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
